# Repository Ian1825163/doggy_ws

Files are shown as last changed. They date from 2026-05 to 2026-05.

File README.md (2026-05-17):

# doggy_ws

## Overview

A 12-DOF quadruped robot project focused on kinematics, servo control, and trajectory generation.

Doggy combines a custom mechanical design, STS-series serial bus servos, inverse/forward kinematics, ROS 2 control nodes, and an Onshape-to-URDF workflow for visualization and future simulation/RL deployment.

## My role

- Designed and implemented the IK/FK pipeline
- Calibrated STS3032 servos
- Generated foot trajectories for standing, walking, and trotting tests
- Integrated control logic with the robot hardware
- Built the ROS 2 workspace for gait control, motor communication, URDF export, and deployment testing

## System architecture

- Hardware: 12-DOF quadruped frame, STS3032 serial bus servos, Teensy motor controller, Jetson Orin Nano, IMU, battery, and custom 3D/CAD components
- Software: ROS 2 Python nodes for keyboard control, gait generation, motor communication, joint-state bridging, safety gating, and RL deployment scaffolding
- Communication: Jetson publishes motor angle commands over USB serial to Teensy; Teensy sends STS bus packets to the servos; feedback bring-up is being tested through a direct STS feedback test node
- Control loop: foot trajectory generation -> IK solver -> 12 motor angle commands -> Teensy serial bridge -> STS3032 servo bus

## Demo

Add videos, GIFs, or images here:

```md
![Doggy CAD overview](docs/cad/doggy-cad-overview.png)
![Doggy front](docs/photos/doggy-front.jpg)
![Doggy side](docs/photos/doggy-side.jpg)
```

Media folders:

- CAD files and screenshots: [`docs/cad/`](docs/cad/)
- Robot photos: [`docs/photos/`](docs/photos/)

## Challenges

- Multiple IK solutions and continuity selection
- Nonlinear calf/knee linkage driven by the third motor
- STS3032 servo calibration and sign convention matching
- Real-world trajectory stability under open-loop control
- Mapping CAD/Onshape joint frames into a usable URDF

## Results

- Robot can stand with commanded servo angles
- IK validated with circular and sinusoidal foot trajectories
- Workspace and reachable foot motion were defined from the kinematic model
- Full four-leg URDF export now includes 16 DOFs, `base_link`, `imu`, and four foot frames
- ROS 2 nodes are available for gait generation, motor communication, joint-state bridging, safety gating, and STS feedback testing

## Next steps

- Open-loop walking validation on hardware
- ROS/URDF visualization and joint-state calibration
- STS3032 feedback readback through Teensy or direct servo bus adapter
- Vision / closed-loop control
- RL policy training and sim-to-real deployment

## Build

```bash
cd ~/doggy_ws
colcon build --symlink-install
source install/setup.bash
```

## Run

Scripted gait bring-up:

```bash
ros2 launch quadruped_bringup bringup.launch.py serial_port:=/dev/ttyACM0 baud_rate:=115200
```

RL deployment scaffold:

```bash
ros2 launch quadruped_bringup rl_bringup.launch.py
```

STS feedback direct-bus test:

```bash
ros2 run quadruped_control sts_feedback_test_node --ros-args \
  -p serial_port:=/dev/ttyUSB0 \
  -p baud_rate:=1000000 \
  -p servo_ids:="[1,2,3,4,5,6,7,8,9,10,11,12]"
```

## Repository layout

```text
doggy_ws/
+-- docs/
|   +-- cad/                  # CAD screenshots, Onshape notes, exported CAD files
|   +-- photos/               # Robot build photos
|   +-- rl_workflow.md        # RL deployment and bring-up notes
+-- src/
|   +-- doggy/                # Onshape-generated URDF, meshes, and config
|   +-- quadruped_bringup/    # ROS 2 launch files
|   +-- quadruped_control/    # Gait, IK, safety, feedback, and motor nodes
```

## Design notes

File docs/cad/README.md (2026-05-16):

# CAD Uploads

Put CAD-related project media here while the Doggy assembly and URDF are still being rebuilt.

Good files to keep here:

- Onshape assembly screenshots.
- Frame and mate connector screenshots.
- Exported STEP/STL snapshots that are useful for review.
- URDF tree screenshots from `check_urdf` or RViz.

Suggested names:

- `doggy-cad-overview.png`
- `doggy-urdf-frames.png`
- `doggy-assembly-notes.md`

Do not put Onshape API keys or private `.env` files in this folder.

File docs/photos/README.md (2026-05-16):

# Robot Photos

Put photos of the physical Doggy robot here.

Suggested names:

- `doggy-front.jpg`
- `doggy-side.jpg`
- `doggy-top.jpg`
- `doggy-wiring.jpg`

After uploading photos, add them to the gallery block in the root `README.md`.

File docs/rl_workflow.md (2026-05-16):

# Doggy RL Deployment Workflow

This is the working plan for moving Doggy from the current ROS 2 gait stack toward an RL policy that can be trained in simulation and deployed on the Jetson.

## Current Mechanical Check

Latest Onshape assembly checked: `doggy_ros_export`

- Estimated total mass from Onshape part mass properties: `1.348 kg`
- Mass-bearing part occurrences found: `44`
- Current local `src/doggy/robot.urdf` is the regenerated full robot export from `doggy_ros_export`.

Largest mass contributors:

| Part | Mass |
| --- | ---: |
| `teensy_battery <1>` | `0.292 kg` |
| `jetson <1>` | `0.253 kg` |
| `body upper plate v2` | `0.0898 kg` |
| `body upper plate v3` | `0.0884 kg` |
| `Feetech STS2032` motors | `0.025 kg` each |
| `foot` | `0.020 kg` each |

Current URDF status:

- `onshape-to-robot doggy` finds all four legs and 16 DOFs.
- `check_urdf src/doggy/robot.urdf` succeeds.
- Root link is `body`.
- Frames exported as links: `base_link`, `imu`, `RL_foot`, `RR_foot`, `FR_foot`, `FL_foot`.
- URDF total inertial mass: `1.348077 kg`.

Regenerate and validate after CAD changes:

```bash
cd ~/doggy_ws/src
onshape-to-robot doggy
cd ~/doggy_ws
check_urdf src/doggy/robot.urdf
```

## Runtime Architecture

Keep motor commands and visualization state separate:

```text
gait_generator_node
  publishes /joint_angles directly in scripted gait mode

policy_node
  publishes /joint_angles_unsafe in RL mode

safety_node
  clamps /joint_angles_unsafe into /joint_angles

motor_control_node
  subscribes /joint_angles
  sends 12 real motor angles to Teensy

joint_state_bridge_node
  subscribes /joint_angles
  computes passive knee angles from nonlinear linkage FK
  publishes /joint_states

robot_state_publisher
  subscribes /joint_states
  publishes TF from the URDF
```

The URDF should include both motor joints and passive knee joints, but the nonlinear relation should not be encoded as a URDF mimic or gear relation.

Use this mapping for the current command order:

```text
/joint_angles:
  LB1 LB2 LB3 | RB1 RB2 RB3 | RF1 RF2 RF3 | LF1 LF2 LF3

Leg names:
  LB -> RL
  RB -> RR
  RF -> FR
  LF -> FL
```

For each leg:

```text
hip_roll  = motor 1
hip_pitch = motor 2
motor3    = real third motor angle
knee      = nonlinear_linkage_fk(motor3)
```

## ROS Nodes

1. `joint_state_bridge_node` implemented in `quadruped_control`

   Inputs:

   - `/joint_angles` as `std_msgs/Float32MultiArray`

   Outputs:

   - `/joint_states` as `sensor_msgs/JointState`

   Responsibilities:

   - Convert degrees to radians.
   - Rename command array indices into URDF joint names.
   - Compute `*_knee` from `*_motor3` using the MATLAB/Python linkage FK.
   - Apply per-leg sign and zero offsets.

   Run:

   ```bash
   ros2 run quadruped_control joint_state_bridge_node
   ```

2. `policy_node` implemented as a deployment scaffold

   Inputs:

   - `/gait_cmd`

   Outputs:

   - `/joint_angles_unsafe`

   Responsibilities:

   - Keep a stable ROS interface for the future trained policy.
   - Publish a safe stand pose while no inference backend is wired.
   - Later: load the trained policy and output 12 motor target angles.

   Run:

   ```bash
   ros2 run quadruped_control policy_node
   ```

3. `safety_node` implemented in `quadruped_control`

   Responsibilities:

   - Gate `/joint_angles_unsafe` into `/joint_angles`.
   - Clamp joint angle commands.
   - Command timeout handling.
   - Publish stand pose on timeout or disabled state.
   - Later: add IMU tilt/fall checks and motor feedback checks.

   Run:

   ```bash
   ros2 run quadruped_control safety_node
   ```

Launch options:

```bash
# Existing scripted gait path, now also publishing /joint_states
ros2 launch quadruped_bringup bringup.launch.py

# RL deployment path:
# policy_node -> safety_node -> /joint_angles -> motor_control_node
ros2 launch quadruped_bringup rl_bringup.launch.py
```

## Calibration Before RL

Finish these before trusting sim-to-real:

1. Motor zero offsets for all 12 actuators.
2. Motor sign convention for all four legs.
3. Passive knee sign and offset:

   ```text
   urdf_knee = sign * linkage_theta4(motor3) + offset
   ```

4. IMU frame orientation against `base_link`.
5. Foot frames at the foot-tip sphere centers.
6. Joint limits checked against physical hard stops.
7. Standing pose verified in RViz and on hardware.

## Training Plan

Preferred setup:

- Train on a desktop/cloud machine with GPU.
- Deploy only the exported policy on Jetson Orin Nano.
- Keep Jetson runtime simple: ROS 2 node, inference, safety clamps, serial motor bridge.

Simulation choices:

- Isaac Lab if GPU training and terrain/domain randomization matter most.
- MuJoCo if fast iteration and easier model debugging matter most.

Policy interface:

- Observation:
  - base orientation and angular velocity
  - commanded velocity
  - 12 motor positions
  - 12 motor velocities when available
  - previous action
  - optional gait phase
  - optional foot contact states
- Action:
  - 12 target motor angles, or 12 residual offsets around a nominal gait
- Control rate:
  - start with `50 Hz`, matching the current gait generator

Rewards:

- velocity tracking
- upright body orientation
- target body height
- low energy / smooth action
- foot clearance during swing
- low foot slip during stance
- joint limit avoidance
- fall penalty

Domain randomization:

- total mass around `1.348 kg`
- per-link mass and COM offsets
- motor strength
- joint damping/friction
- ground friction
- IMU noise and bias
- command latency
- battery/Jetson payload variation

## Deployment Stages

1. URDF validation

   - Fix `frame_base_link`.
   - Export full URDF.
   - Check root link is body/base.
   - Confirm all foot frames and IMU frame appear.
   - Confirm mass and inertials are reasonable.

2. Visualization bridge

   - Add `joint_state_bridge_node`.
   - Publish `/joint_states` from existing `/joint_angles`.
   - Confirm RViz motion matches the physical leg direction.

3. Hardware baseline

   - Stand pose only.
   - Slow scripted leg sweep.
   - Low-speed gait with rosbag recording.
   - Check communication drop rate.

4. Simulation baseline

   - Import URDF/MJCF/USD.
   - Reproduce standing pose.
   - Reproduce current scripted gait.
   - Validate foot locations and joint signs.

5. RL training

   - Start with stand/balance.
   - Add commanded forward velocity.
   - Add yaw command.
   - Add terrain and pushes only after flat ground works.

6. Sim-to-real rollout

   - Policy disabled by default.
   - E-stop active.
   - Test on stand or suspended robot first.
   - Touchdown test at low action scale.
   - Increase action scale and command speed gradually.

## Bag Topics

Record these for debugging:

```bash
ros2 bag record \
  /joint_angles \
  /joint_states \
  /imu \
  /gait_cmd \
  /comm_stats \
  /teensy_ack \
  /teensy_hb
```

Add later when available:

- `/cmd_vel`
- `/motor_feedback`
- `/foot_contacts`
- `/policy_debug`

## STS3032 Feedback Bring-Up

Current `src/teensy_motor.ino` writes STS sync-write packets on `Serial4`, but
it does not yet forward USB packets to the STS bus or send motor feedback back
to Jetson. To test feedback now, connect Jetson to the STS bus through a direct
USB servo adapter, or add a Teensy bridge/readback firmware path first.

Direct bus feedback test:

```bash
ros2 run quadruped_control sts_feedback_test_node --ros-args \
  -p serial_port:=/dev/ttyUSB0 \
  -p baud_rate:=1000000 \
  -p servo_ids:="[1,2,3,4,5,6,7,8,9,10,11,12]"
```

Watch the raw JSON:

```bash
ros2 topic echo /sts_feedback_raw
```

The test node reads from register `56` with length `8`, which covers present
position plus the adjacent raw status bytes used for early bring-up.

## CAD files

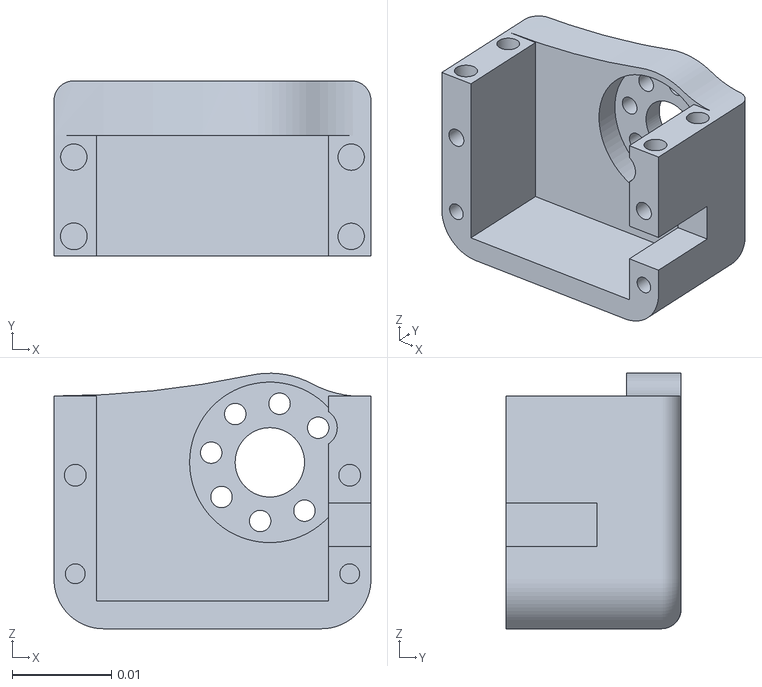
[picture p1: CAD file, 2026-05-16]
src/doggy/assets/hipjoint_v4__2.stl
0.032 x 0.0177 x 0.0258

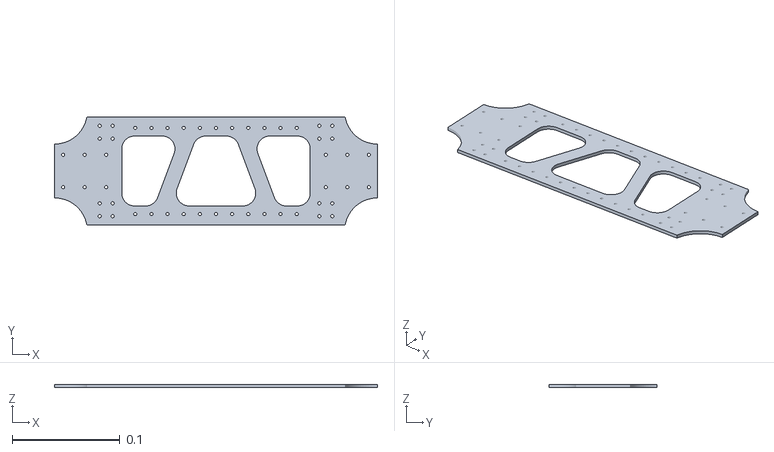
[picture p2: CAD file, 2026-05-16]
src/doggy/assets/身體上板_v3.stl
0.3 x 0.1 x 0.003

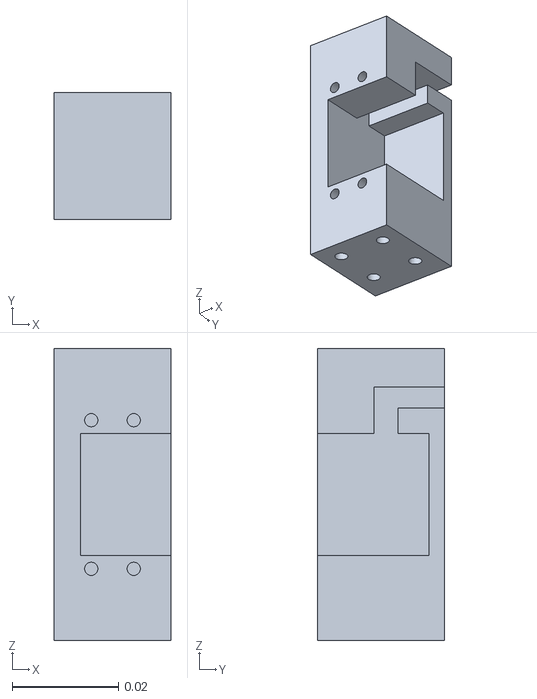
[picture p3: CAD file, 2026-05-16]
src/doggy/assets/motor_holder_for_onshape_mir.stl
0.022 x 0.024 x 0.055

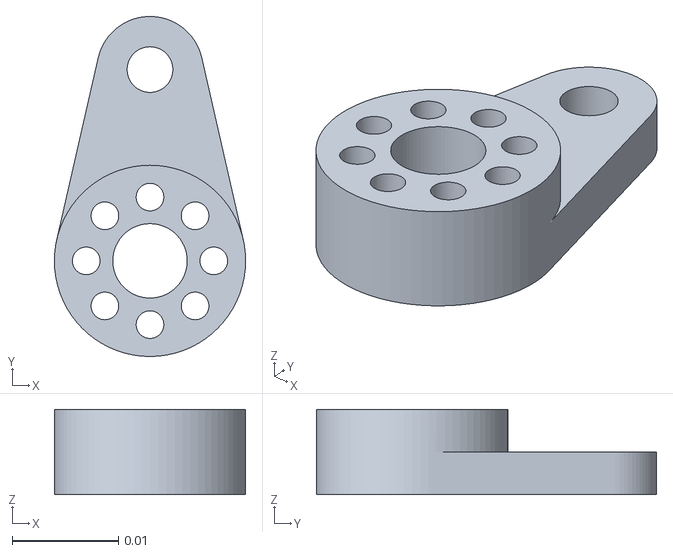
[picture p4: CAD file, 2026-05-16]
src/doggy/assets/linkage_a_v2_0713_mir.stl
0.018 x 0.032 x 0.008

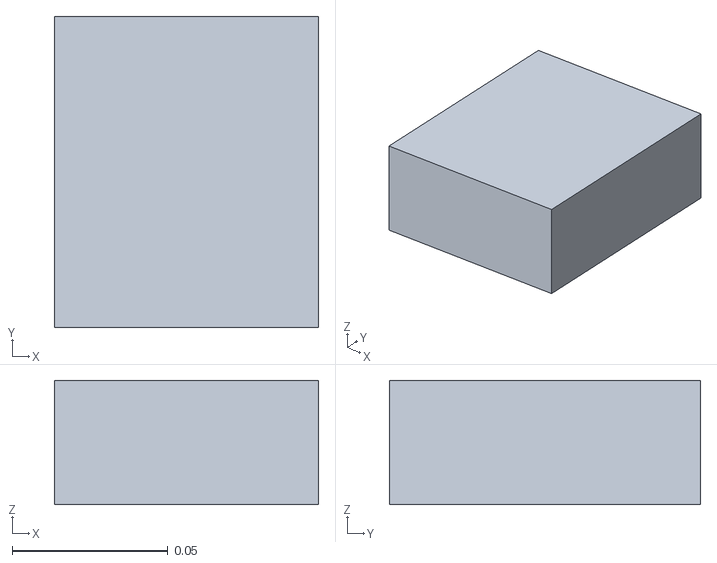
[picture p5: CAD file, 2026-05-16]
src/doggy/assets/part_1__2.stl
0.085 x 0.1 x 0.04

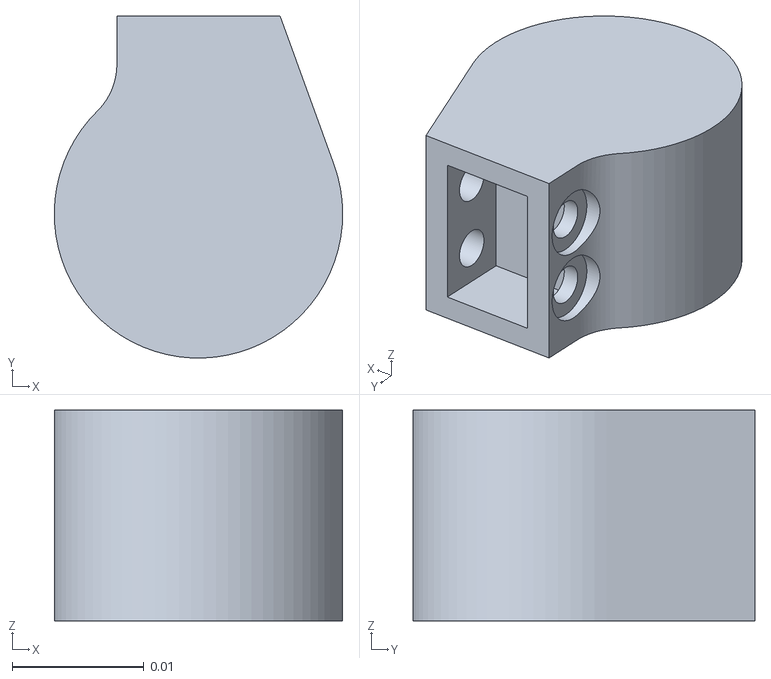
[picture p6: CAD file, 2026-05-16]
src/doggy/assets/角頭v2.stl
0.0219 x 0.026 x 0.016

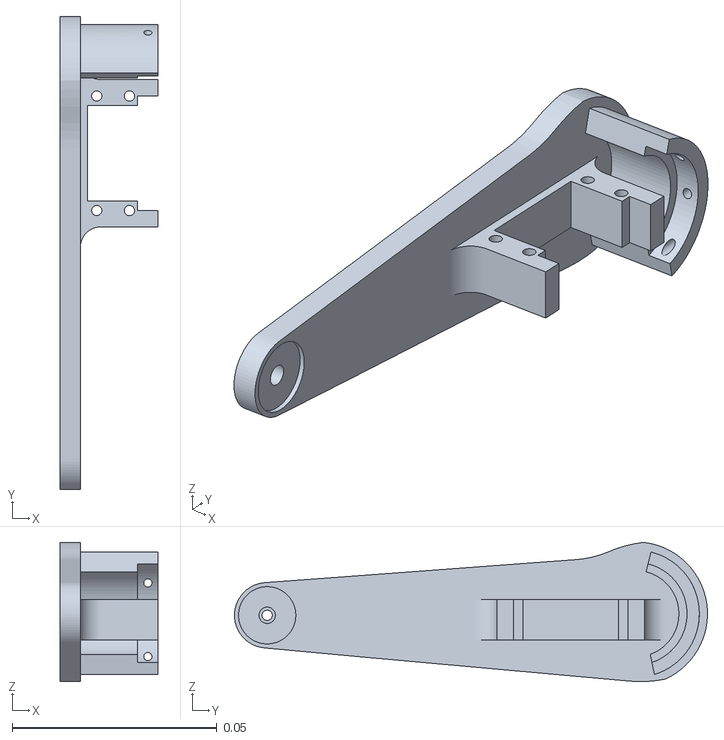
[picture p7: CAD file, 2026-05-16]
src/doggy/assets/out_leg_v4_mirrored.stl
0.024 x 0.116 x 0.034

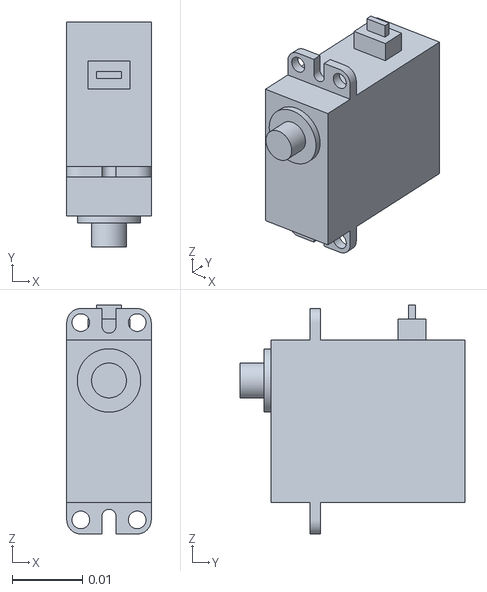
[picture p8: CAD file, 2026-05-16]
src/doggy/assets/feetech_sts2032_20g.stl
0.012 x 0.0319 x 0.0325

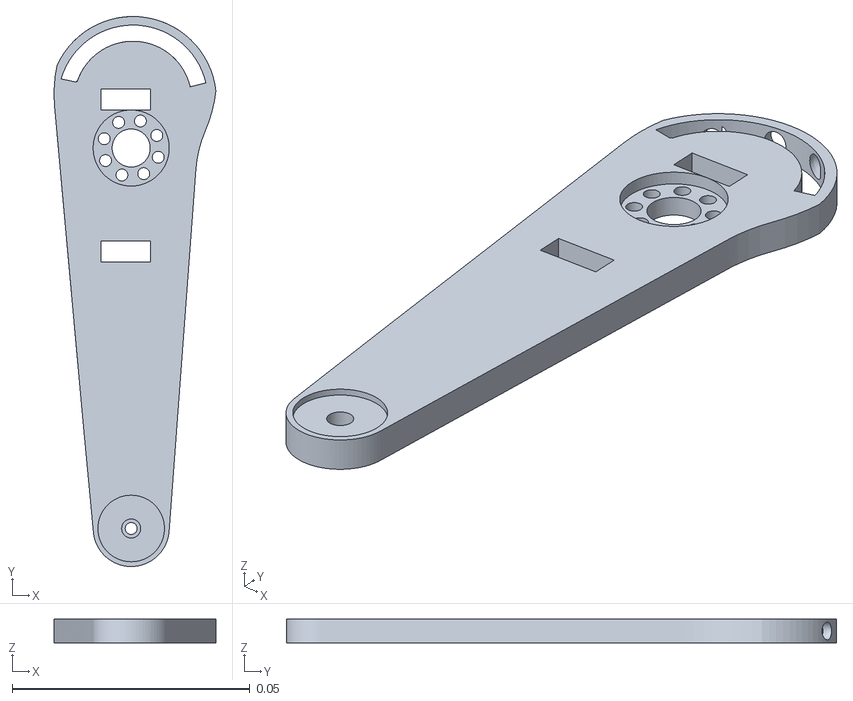
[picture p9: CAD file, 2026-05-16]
src/doggy/assets/inner_leg_v4__2.stl
0.034 x 0.116 x 0.005

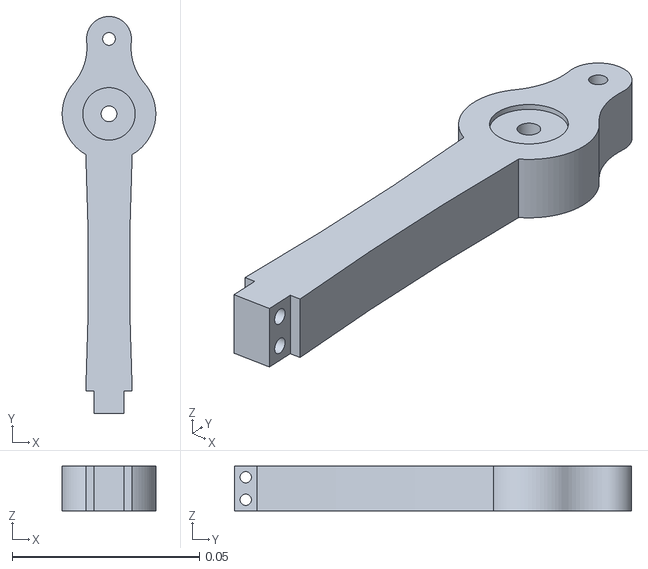
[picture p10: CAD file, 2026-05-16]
src/doggy/assets/foot_v4.stl
0.025 x 0.106 x 0.012

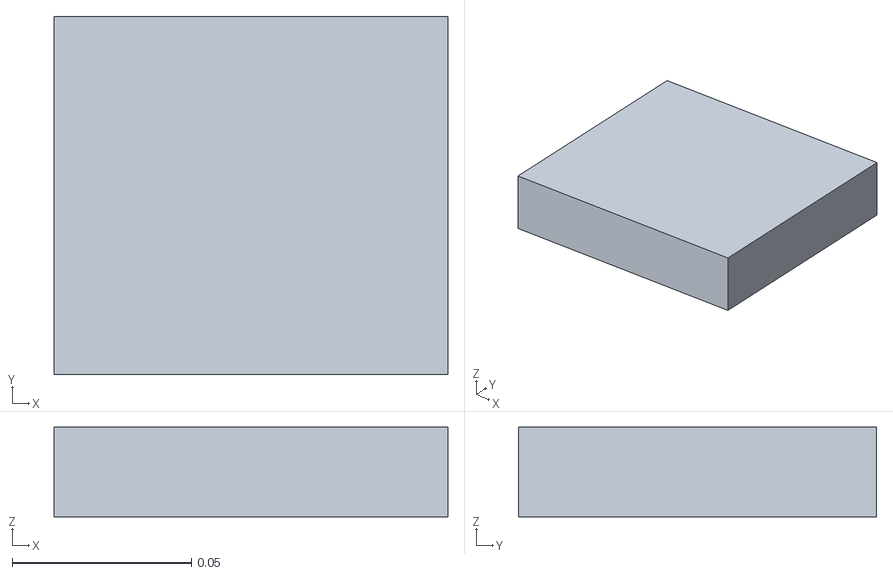
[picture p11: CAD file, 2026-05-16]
src/doggy/assets/part_1.stl
0.11 x 0.1 x 0.025

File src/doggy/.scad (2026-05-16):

% scale(1000) import(".");

// Append pure shapes (cube, cylinder and sphere), e.g:
// cube([10, 10, 10], center=true);
// cylinder(r=10, h=10, center=true);
// sphere(10);

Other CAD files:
src/doggy/assets/motor_holder_for_onshape.stl
src/doggy/assets/out_leg_v4__2.stl
src/doggy/assets/out_leg_v4.stl
src/doggy/assets/inner_leg_v4_mirrored.stl
src/doggy/foot_tip.scad
src/doggy/assets/calf.scad
src/doggy/assets/foot.scad
src/doggy/assets/foot_tip.scad
src/doggy/assets/hipjoint_v4.stl
src/doggy/assets/inner_leg_v4.stl
src/doggy/assets/身體上板_v2.stl

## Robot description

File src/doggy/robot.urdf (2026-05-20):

<?xml version="1.0" ?>
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
<robot name="doggy">
  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
  <link name="body">
    <inertial>
      <origin xyz="7.47198e-16 -5.12135e-17 0.0124695" rpy="0 0 0"/>
      <mass value="0.918789"/>
      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
    </inertial>
    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
  </link>
  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
  <link name="imu">
    <origin xyz="0 0 0" rpy="0 -0 0"/>
    <inertial>
      <origin xyz="0 0 0" rpy="0 0 0"/>
      <mass value="1e-9"/>
      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
    </inertial>
  </link>
  <joint name="imu_frame" type="fixed">
    <origin xyz="-2.89644e-18 -2.1684e-18 -0.0145" rpy="0 -0 3.14159"/>
    <parent link="body"/>
    <child link="imu"/>
    <axis xyz="0 0 0"/>
  </joint>
  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
  <link name="base_link">
    <origin xyz="0 0 0" rpy="0 -0 0"/>
    <inertial>
      <origin xyz="0 0 0" rpy="0 0 0"/>
      <mass value="1e-9"/>
      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
    </inertial>
  </link>
  <joint name="base_link_frame" type="fixed">
    <origin xyz="-2.89644e-18 -2.35336e-18 0.003" rpy="-3.24138e-43 -8.96831e-44 -3.14159"/>
    <parent link="body"/>
    <child link="base_link"/>
    <axis xyz="0 0 0"/>
  </joint>
  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
  <link name="hipjoint">
    <inertial>
      <origin xyz="-0.00584991 -0.00133744 -0.0104817" rpy="0 0 0"/>
      <mass value="0.0326833"/>
      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
    </inertial>
    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
  </link>
  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
  <link name="thigh_mir">
    <inertial>
      <origin xyz="0.000153018 -0.019063 -0.0124043" rpy="0 0 0"/>
      <mass value="0.0369251"/>
      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
    </inertial>
    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
  </link>
  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
  <link name="calf">
    <inertial>
      <origin xyz="3.21658e-05 0.0313528 -0.0050139" rpy="0 0 0"/>
      <mass value="0.023"/>
      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
    </inertial>
    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
  </link>
  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
  <link name="RL_foot">
    <origin xyz="0 0 0" rpy="0 -0 0"/>
    <inertial>
      <origin xyz="0 0 0" rpy="0 0 0"/>
      <mass value="1e-9"/>
      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
    </inertial>
  </link>
  <joint name="RL_foot_frame" type="fixed">
    <origin xyz="-3e-06 0.0919 -0.005" rpy="-1.5708 1.27732e-31 3.14159"/>
    <parent link="calf"/>
    <child link="RL_foot"/>
    <axis xyz="0 0 0"/>
  </joint>
  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
  <joint name="RL_knee" type="revolute">
    <origin xyz="2.30043e-13 -0.08 -0.007" rpy="6.12323e-17 -6.30424e-31 1.5708"/>
    <parent link="thigh_mir"/>
    <child link="calf"/>
    <axis xyz="0 0 1"/>
    <limit effort="10" velocity="10" lower="-1.309" upper="1.5708"/>
  </joint>
  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
  <joint name="RL_hip_pitch" type="revolute">
    <origin xyz="-1.11022e-16 0.0187 -0.0117" rpy="-1.5708 -3.06162e-16 -3.14159"/>
    <parent link="hipjoint"/>
    <child link="thigh_mir"/>
    <axis xyz="0 0 1"/>
    <limit effort="10" velocity="10" lower="-1.5708" upper="0.174533"/>
  </joint>
  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
  <joint name="RL_hip_roll" type="revolute">
    <origin xyz="0.125 -0.036 -0.00279" rpy="-3.14159 1.5708 0"/>
    <parent link="body"/>
    <child link="hipjoint"/>
    <axis xyz="0 0 1"/>
    <limit effort="10" velocity="10" lower="-0.349066" upper="0.174533"/>
  </joint>
  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
  <link name="hipjoint_mir">
    <inertial>
      <origin xyz="-0.00584991 0.00133744 -0.0104817" rpy="0 0 0"/>
      <mass value="0.0326833"/>
      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
    </inertial>
    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
  </link>
  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
  <link name="thigh_mir_2">
    <inertial>
      <origin xyz="0.000153018 -0.019063 -0.0124043" rpy="0 0 0"/>
      <mass value="0.0369251"/>
      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
    </inertial>
    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
  </link>
  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
  <link name="calf_2">
    <inertial>
      <origin xyz="3.21658e-05 0.0313528 -0.0060139" rpy="0 0 0"/>
      <mass value="0.023"/>
      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
    </inertial>
    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
  </link>
  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
  <link name="FL_foot">
    <origin xyz="0 0 0" rpy="0 -0 0"/>
    <inertial>
      <origin xyz="0 0 0" rpy="0 0 0"/>
      <mass value="1e-9"/>
      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
    </inertial>
  </link>
  <joint name="FL_foot_frame" type="fixed">
    <origin xyz="-3e-06 0.0919 -0.006" rpy="-1.5708 -5.14606e-32 3.14159"/>
    <parent link="calf_2"/>
    <child link="FL_foot"/>
    <axis xyz="0 0 0"/>
  </joint>
  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
  <joint name="FL_knee" type="revolute">
    <origin xyz="2.30081e-13 -0.08 -0.006" rpy="-6.70532e-30 -7.2455e-30 1.5708"/>
    <parent link="thigh_mir_2"/>
    <child link="calf_2"/>
    <axis xyz="0 0 1"/>
    <limit effort="10" velocity="10" lower="-1.309" upper="1.5708"/>
  </joint>
  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
  <joint name="FL_hip_pitch" type="revolute">
    <origin xyz="1.25767e-17 -0.0187 -0.0117" rpy="1.5708 -9.36772e-31 -3.14159"/>
    <parent link="hipjoint_mir"/>
    <child link="thigh_mir_2"/>
    <axis xyz="0 0 1"/>
    <limit effort="10" velocity="10" lower="-1.5708" upper="0.174533"/>
  </joint>
  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
  <joint name="FL_hip_roll" type="revolute">
    <origin xyz="-0.125 -0.036 -0.00279" rpy="-1.51223e-15 1.5708 0"/>
    <parent link="body"/>
    <child link="hipjoint_mir"/>
    <axis xyz="0 0 1"/>
    <limit effort="10" velocity="10" lower="-0.174533" upper="0.349066"/>
  </joint>
  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
  <link name="hipjoint_2">
    <inertial>
      <origin xyz="-0.00584991 -0.00133744 -0.0104817" rpy="0 0 0"/>
      <mass value="0.0326833"/>
      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
    </inertial>
    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
  </link>
  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
  <link name="thigh">
    <inertial>
      <origin xyz="-5.38791e-05 0.013613 -0.0118373" rpy="0 0 0"/>
      <mass value="0.0619252"/>
      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
    </inertial>
    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
  </link>
  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
  <link name="calf_3">
    <inertial>
      <origin xyz="3.21658e-05 -0.0313528 -0.0059861" rpy="0 0 0"/>
      <mass value="0.023"/>
      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
    </inertial>
    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
  </link>
  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
  <link name="FR_foot">
    <origin xyz="0 0 0" rpy="0 -0 0"/>
    <inertial>
      <origin xyz="0 0 0" rpy="0 0 0"/>
      <mass value="1e-9"/>
      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
    </inertial>
  </link>
  <joint name="FR_foot_frame" type="fixed">
    <origin xyz="-3e-06 -0.0919 -0.006" rpy="1.5708 5.52464e-33 3.14159"/>
    <parent link="calf_3"/>
    <child link="FR_foot"/>
    <axis xyz="0 0 0"/>
  </joint>
  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
  <joint name="FR_knee" type="revolute">
    <origin xyz="2.29983e-13 0.08 -0.006" rpy="3.36134e-27 -4.48177e-28 -1.5708"/>
    <parent link="thigh"/>
    <child link="calf_3"/>
    <axis xyz="0 0 1"/>
    <limit effort="10" velocity="10" lower="-1.309" upper="1.5708"/>
  </joint>
  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
  <joint name="FR_hip_pitch" type="revolute">
    <origin xyz="-1.01048e-16 0.0187 -0.0117" rpy="-1.5708 8.48025e-30 -3.14159"/>
    <parent link="hipjoint_2"/>
    <child link="thigh"/>
    <axis xyz="0 0 1"/>
    <limit effort="10" velocity="10" lower="-0.174533" upper="1.5708"/>
  </joint>
  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
  <joint name="FR_hip_roll" type="revolute">
    <origin xyz="-0.125 0.036 -0.00279" rpy="-6.89354e-17 1.5708 0"/>
    <parent link="body"/>
    <child link="hipjoint_2"/>
    <axis xyz="0 0 1"/>
    <limit effort="10" velocity="10" lower="-0.349066" upper="0.174533"/>
  </joint>
  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
  <link name="hipjoint_mir_2">
    <inertial>
      <origin xyz="-0.00584991 0.00133744 -0.0104817" rpy="0 0 0"/>
      <mass value="0.0326833"/>
      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
    </inertial>
    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
  </link>
  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
  <link name="thigh_2">
    <inertial>
      <origin xyz="-5.38791e-05 0.013613 -0.0118373" rpy="0 0 0"/>
      <mass value="0.0619252"/>
      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
    </inertial>
    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
  </link>
  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
  <link name="calf_4">
    <inertial>
      <origin xyz="3.21658e-05 -0.0313528 -0.0059861" rpy="0 0 0"/>
      <mass value="0.023"/>
      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
    </inertial>
    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
  </link>
  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
  <link name="RR_foot">
    <origin xyz="0 0 0" rpy="0 -0 0"/>
    <inertial>
      <origin xyz="0 0 0" rpy="0 0 0"/>
      <mass value="1e-9"/>
      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
    </inertial>
  </link>
  <joint name="RR_foot_frame" type="fixed">
    <origin xyz="-3e-06 -0.0919 -0.006" rpy="1.5708 -1.39172e-31 3.14159"/>
    <parent link="calf_4"/>
    <child link="RR_foot"/>
    <axis xyz="0 0 0"/>
  </joint>
  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
  <joint name="RR_knee" type="revolute">
    <origin xyz="2.30041e-13 0.08 -0.006" rpy="-1.49884e-29 4.87234e-30 -1.5708"/>
    <parent link="thigh_2"/>
    <child link="calf_4"/>
    <axis xyz="0 0 1"/>
    <limit effort="10" velocity="10" lower="-1.5708" upper="1.309"/>
  </joint>
  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
  <joint name="RR_hip_pitch" type="revolute">
    <origin xyz="1.25767e-17 -0.0187 -0.0117" rpy="1.5708 -3.24173e-30 3.14159"/>
    <parent link="hipjoint_mir_2"/>
    <child link="thigh_2"/>
    <axis xyz="0 0 1"/>
    <limit effort="10" velocity="10" lower="-0.174533" upper="1.5708"/>
  </joint>
  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

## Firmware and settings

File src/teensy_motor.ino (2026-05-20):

#include <Arduino.h>
#include <math.h>
#include <IntervalTimer.h>
#include <stdlib.h>
#include <string.h>


struct Vec3 {
  double x, y, z;
};
class Leg;  


// -----------------------------
//  Config
// -----------------------------
static constexpr uint32_t BAUD_SERVO = 1000000;
static constexpr uint32_t BAUD_USB   = 115200;

// ROS bridge mode:
//   Jetson -> Teensy: $ANGLES,<seq>,d1,d2,...,d12\n
//   Teensy -> Jetson: $ACK,<seq>,1\n and $HB,<seq>\n
static constexpr bool ENABLE_ROS_BRIDGE = true;
static constexpr uint32_t HEARTBEAT_MS = 100;          // 10 Hz
static constexpr uint32_t COMMAND_TIMEOUT_MS = 500;    // fall back to stand
static constexpr uint32_t FAILSAFE_STAND_MS = 100;     // resend stand at 10 Hz


static constexpr uint16_t CENTER_TICK = 2048;   // STS 12-bit center
static constexpr uint16_t GOAL_SPEED  = 1000;   // 0x03E8
static constexpr uint16_t GOAL_TIME   = 200;    // don't use 0 at first (gentler)


static constexpr bool ENABLE_TIMER = true;     // false: test stable position; true for real time control
static constexpr bool ENABLE_TRAJ  = true;    
static constexpr uint32_t CTRL_US  = 20000;     // 20ms => 50Hz


// Angle safety clamp (deg)
static constexpr double LIMIT_DEG = 70.0;


const double T = 2.0;
const double omega = 2.0 * M_PI / T;
const double lift = 10.0;
const double disp = 30.0;


//gait control parameter
static double phase = 0.0;
const double phaseRate = 1.0 / T;   // 1/T cycle per second




// -----------------------------
//  Utils
// -----------------------------
inline double clampd(double v, double lo, double hi){
  return (v < lo) ? lo : (v > hi) ? hi : v;
}
inline double deg2rad(double d){ return d * M_PI / 180.0; }
inline double rad2deg(double r){ return r * 180.0 / M_PI; }


inline int16_t wrap4096(int32_t v){
  v %= 4096;
  if(v < 0) v += 4096;
  return (int16_t)v;
}


// rad -> tick offset (can be negative)
inline int32_t rad2tick_offset(double rad){
  return (int32_t)lround(rad * (4096.0 / (2.0*M_PI)));
}


// center + rad (safe wrap 0..4095)
inline uint16_t centerPlusRad(double rad){
  int32_t goal = (int32_t)CENTER_TICK + rad2tick_offset(rad);
  return (uint16_t)wrap4096(goal);
}


inline double wrapPi(double a){
  while(a <= -M_PI) a += 2.0*M_PI;
  while(a >   M_PI) a -= 2.0*M_PI;
  return a;
}
inline double wrap01(double p){
  p = fmod(p, 1.0);
  if(p < 0) p+=1;
  return p;
}
inline double angDiff(double a, double b){
  return wrapPi(a - b);
}




// -----------------------------
//  Debug shared (main loop prints)
// -----------------------------
volatile double debug_x = 0, debug_y = 0, debug_z = 0;
volatile double debug_a1 = 0, debug_a2 = 0, debug_a3 = 0;


unsigned long lastPrintTime = 0;


// -----------------------------
//  Leg class (你的 IK 保留，微調安全)
// -----------------------------
class Leg {
public:
  bool inited_c;
  double last_c_local;


    // --- NEW: FK 4-bar state (theta4 root memory) ---
  bool inited_theta4;
  int  last_theta4_choice;   // 1 or 2


  // --- NEW: IK branch selection state (c1/c2 hysteresis) ---
  bool inited_pick;
  int  last_pick;            // 1=c1, 2=c2




  const double L1;
  const int L2;
  const int L3;
  const int L4;
  const double h;
  const int r;


  // NEW: FK params
  const int R3;
  const int R4;


  double angle1;
  double angle2;
  double angle3;
  double pos[3];


  double z_on;
  double z_off;


  bool use_c2;


  Leg();
  void setTargetPosition(double x, double y, double z);
  void setTargetAngle(double a1, double a2, double a3);
  void computeIK();
    // --- NEW: FK + selection ---
  Vec3 fkEndEffector(double alp, double bet, double gamm, bool do_update);
  void computeIK_FKSelect();      


};


void lift_trajectory(Leg& leg, double t);
void sinusoidal_trajectory(Leg& leg, double p, double duty);
void standing_pose(Leg& leg);
void squat_pose(Leg& leg);


void trot(Leg& RB, Leg& RF, Leg& LB, Leg& LF, double phase);
void walk(Leg& RB, Leg& RF, Leg& LB, Leg& LF, double phase);
void lean(Leg& RB, Leg& RF, Leg& LB, Leg& LF);


void sendMotorPacketDeg(double d1, double d2, double d3,
                        double d4, double d5, double d6,
                        double d7, double d8, double d9,
                        double d10,double d11,double d12);
void sendMotorPacketDegArray(const double deg[12]);
void sendStandPose();
void handleUsbSerial();
void handleCommandLine(const char* line);
bool parseAnglesLine(const char* line, uint32_t& seq, double deg[12]);
uint32_t parseSeqBestEffort(const char* line);
void sendAck(uint32_t seq, bool ok);
void sendHeartbeat();




Leg::Leg()
  : inited_c(false),
    last_c_local(0.0),    
    inited_theta4(false),
    last_theta4_choice(1),
    inited_pick(false),
    last_pick(1),
    L1(26.086),
    L2(80),
    L3(80),
    L4(20),
    h(28.5),
    r(22),
    R3(20),
    R4(80),


    angle1(M_PI/2),
    angle2(M_PI/2),
    angle3(M_PI/2),
    z_on(-123.0),
    z_off(-123.0),
    use_c2(false)
   
{
  pos[0] = 26.086;
  pos[1] = 0.0;
  pos[2] = -155.0;
}


void Leg::setTargetPosition(double x, double y, double z){
  pos[0] = x;
  pos[1] = y;
  pos[2] = z;
}


void Leg::computeIK(){
  double x = pos[0], y = pos[1], z = pos[2];


  double l2 = x*x + y*y + z*z;
  double l  = sqrt(l2);
  if(l < 1e-6) l = 1e-6;


  double d2 = l2 - L1*L1;
  if(d2 < 0) d2 = 0;
  double d  = sqrt(d2);
  if(d < 1e-6) d = 1e-6;


  // knee geometry
  double cosK = (L1*L1 + (double)L2*L2 + (double)L3*L3 - l2) / (2.0*L2*L3);
  cosK = clampd(cosK, -1.0, 1.0);
  double theta_k = acos(cosK);


  // theta_b
  double s1 = clampd(y/d, -1.0, 1.0);
  double cos2 = ((double)L2*L2 + d*d - (double)L3*L3) / (2.0*L2*d);
  cos2 = clampd(cos2, -1.0, 1.0);
  double theta_b = M_PI/2.0 - (asin(s1) + acos(cos2));


  // theta_a
  double ca = clampd(L1 / l, -1.0, 1.0);
  double theta_a = atan2(x, fabs(z)) + acos(ca) - M_PI/2.0;


  // theta_c (your linkage)
  double A = 2.0*r*(L4*cos(theta_k) + L2);
  double B = 6.0*r;
  double C = (double)r*r + pow((double)L2 + L4*cos(theta_k), 2)
           + 9.0 + pow(L4*sin(theta_k) - h, 2) - (double)L3*L3;


  double disc = (A*B)*(A*B) - (A*A - C*C)*(B*B - C*C);
  double sq = sqrt(fmax(disc, 0.0));


  double Y1 = -A*B + sq;
  double Y2 = -A*B - sq;
  double X  = A*A - C*C;
  double c1 = wrapPi(atan2(Y1, X));
  double c2 = wrapPi(atan2(Y2, X));


  // adjust the new anhle value to be neraest to ref (+-2pi）, avoid jumping sol
  auto unwrapToNear = [&](double a, double ref){
      return ref + angDiff(a, ref);   // angDiff : (-pi,pi]
  };
  double z_now = z; //get z value


  if(!this->inited_c){
      // determine first theta_c
      if(z_now >= this->z_on) this->last_c_local = c1;
      else {
        this->use_c2 = true;
        this->last_c_local = c2;
      }
      this->inited_c = true;
  }
  else {
      double c1u = unwrapToNear(c1, this->last_c_local);
      double c2u = unwrapToNear(c2, this->last_c_local);


      if(this->use_c2){
          if(z_now >= this->z_off) {
            this->use_c2 = false;
            this->last_c_local = c1u;
          }
          else this->last_c_local = c2u;
          }
      else {
        if(z_now >= this->z_on){
          double err1 = fabs(c1u - this->last_c_local);
          double err2 = fabs(c2u - this->last_c_local);
          err1 = min(err1, 2*M_PI - err1);
          err2 = min(err2, 2*M_PI - err2);
          if (err1 <= err2)
              this->last_c_local = c1u;
          else
              this->last_c_local = c2u;


        }
        else {
          this->last_c_local = c2u;
          this->use_c2 = true;


        }
      }
  }


  double chosen = this->last_c_local;


  // --- 5. Store Final Angles ---
  this->angle1 = wrapPi(theta_a);
  this->angle2 = wrapPi(theta_b);
  this->angle3 = chosen;   // wrap to (-pi,pi)


}
// apply R = Ry(alp) * Rx(bet)
static inline Vec3 R_apply(double alp, double bet, const Vec3& v){
  double cb = cos(bet), sb = sin(bet);
  // Rx(bet)
  Vec3 v1 { v.x, cb*v.y + sb*v.z, -sb*v.y + cb*v.z };


  double ca = cos(alp), sa = sin(alp);
  // Ry(alp)
  Vec3 v2 { ca*v1.x - sa*v1.z, v1.y, sa*v1.x + ca*v1.z };
  return v2;
}


Vec3 Leg::fkEndEffector(double alp, double bet, double gamm, bool do_update){
  // --- theta4 candidates (same as MATLAB) ---
  double a_ = r * sin(gamm);
  double R1_ = sqrt(a_*a_ + h*h);
  double R2_ = sqrt((double)R4*R4 - pow(r*cos(gamm) - 3.0, 2)); // R2 = sqrt(R4^2-(r*cos(g)-3)^2)
  double theta1 = atan2(h, a_);


  double A = 2.0*R1_*R3*sin(theta1);
  double B = 2.0*R1_*R3*cos(theta1) - 2.0*R3*R4;
  double C = R1_*R1_ - R2_*R2_ + (double)R3*R3 + (double)R4*R4 - 2.0*R1_*R4*cos(theta1);


  double disc = C*C * (A*A + B*B - C*C);
  disc = fmax(disc, 0.0);
  double sq = sqrt(disc);


  double th4_1 = atan2(-A*B + sq, A*A - C*C);
  double th4_2 = atan2(-A*B - sq, A*A - C*C);


  // --- error metric (distance should be L3=80) ---
  // B_local_check = [r*cos(g); r*sin(g); h]
  double Bx = r*cos(gamm);
  double By = r*sin(gamm);
  double Bz = h;


  // C1_local = [3; R4 + R3*cos(th4); R3*sin(th4)]
  auto distErr = [&](double th4){
    double C1x = 3.0;
    double C1y = (double)R4 + (double)R3 * cos(th4);
    double C1z = (double)R3 * sin(th4);
    double dx = Bx - C1x, dy = By - C1y, dz = Bz - C1z;
    double d = sqrt(dx*dx + dy*dy + dz*dz);
    return fabs(d - (double)L3);
  };


  double e1 = distErr(th4_1);
  double e2 = distErr(th4_2);


  // --- hysteresis keep continuity (same spirit as MATLAB) ---
  if(!inited_theta4){
    last_theta4_choice = (e1 <= e2) ? 1 : 2;
    inited_theta4 = true;
  }else{
    const double threshold = 0.4;
    if(last_theta4_choice == 1){
      if(e2 < e1 - threshold) last_theta4_choice = 2;
    }else{
      if(e1 < e2 - threshold) last_theta4_choice = 1;
    }
  }


  // if evaluating only, DO NOT update memory
  int choice = last_theta4_choice;
  if(!do_update){
    // compute what choice would be, without changing stored
    choice = (e1 <= e2) ? 1 : 2;
    const double threshold = 0.4;
    if(last_theta4_choice == 1){
      if(e2 < e1 - threshold) choice = 2;
      else choice = 1;
    }else{
      if(e1 < e2 - threshold) choice = 1;
      else choice = 2;
    }
  }


  double th4 = (choice == 1) ? th4_1 : th4_2;


  // if do_update=true, commit
  if(do_update){
    last_theta4_choice = choice;
  }


  // --- compute E_local and transform to global ---
  // D_local = [0; R4; 0]
  // E_local = D_local - [0; R4*cos(th4); R4*sin(th4)] = [0; R4*(1-cos); -R4*sin]
  Vec3 E_local { 0.0, (double)R4 * (1.0 - cos(th4)), -(double)R4 * sin(th4) };


  // sub-assembly origin offset: p0 = R_apply(alp,bet, [L1,0,0])
  Vec3 p0 = R_apply(alp, bet, {L1, 0.0, 0.0});


  // E_global = p0 + R_apply(alp,bet, E_local)
  Vec3 Eg = R_apply(alp, bet, E_local);
  Eg.x += p0.x; Eg.y += p0.y; Eg.z += p0.z;


  return Eg;
}
void Leg::computeIK_FKSelect(){
  double x = pos[0], y = pos[1], z = pos[2];


  // ----- IK a,b,k (same as your computeIK) -----
  double l2 = x*x + y*y + z*z;
  double l  = sqrt(l2);
  if(l < 1e-6) l = 1e-6;


  double d2 = l2 - L1*L1;
  if(d2 < 0) d2 = 0;
  double d  = sqrt(d2);
  if(d < 1e-6) d = 1e-6;


  double cosK = (L1*L1 + (double)L2*L2 + (double)L3*L3 - l2) / (2.0*L2*L3);
  cosK = clampd(cosK, -1.0, 1.0);
  double theta_k = acos(cosK);


  double s1 = clampd(y/d, -1.0, 1.0);
  double cos2 = ((double)L2*L2 + d*d - (double)L3*L3) / (2.0*L2*d);
  cos2 = clampd(cos2, -1.0, 1.0);
  double theta_b = M_PI/2.0 - (asin(s1) + acos(cos2));


  double ca = clampd(L1 / l, -1.0, 1.0);
  double theta_a = atan2(x, fabs(z)) + acos(ca) - M_PI/2.0;


  // ----- IK theta_c roots -----
  double A = 2.0*r*(L4*cos(theta_k) + L2);
  double B = 6.0*r;
  double C = (double)r*r + pow((double)L2 + L4*cos(theta_k), 2)
           + 9.0 + pow(L4*sin(theta_k) - h, 2) - (double)L3*L3;


  double disc = (A*B)*(A*B) - (A*A - C*C)*(B*B - C*C);
  double sq = sqrt(fmax(disc, 0.0));


  double Y1 = -A*B + sq;
  double Y2 = -A*B - sq;
  double X  = A*A - C*C;


  double c1 = wrapPi(atan2(Y1, X));
  double c2 = wrapPi(atan2(Y2, X));


  // unwrap near last_c_local for continuity
  auto unwrapToNear = [&](double a, double ref){
    return ref + angDiff(a, ref);
  };


  double c1u = c1, c2u = c2;
  if(inited_c){
    c1u = unwrapToNear(c1, last_c_local);
    c2u = unwrapToNear(c2, last_c_local);
  }


  // ----- evaluate both by FK end-effector error -----
  Vec3 E1 = fkEndEffector(theta_a, theta_b, c1u, false);
  Vec3 E2 = fkEndEffector(theta_a, theta_b, c2u, false);


  auto norm3 = [](double dx,double dy,double dz){
    return sqrt(dx*dx + dy*dy + dz*dz);
  };


  double pos_err1 = norm3(E1.x-x, E1.y-y, E1.z-z);
  double pos_err2 = norm3(E2.x-x, E2.y-y, E2.z-z);


  double cont1 = inited_c ? fabs(c1u - last_c_local) : 0.0;
  double cont2 = inited_c ? fabs(c2u - last_c_local) : 0.0;


  // weights: match MATLAB
  const double w_pos  = 1.0;
  const double w_cont = 0.05;
  const double hys    = 0.5;


  double J1 = w_pos*pos_err1 + w_cont*cont1;
  double J2 = w_pos*pos_err2 + w_cont*cont2;


  int pick;
  if(!inited_pick){
    pick = (J1 <= J2) ? 1 : 2;
    inited_pick = true;
    inited_c = true;
  }else{
    if(last_pick == 1){
      pick = (J2 < J1 - hys) ? 2 : 1;
    }else{
      pick = (J1 < J2 - hys) ? 1 : 2;
    }
  }


  double chosen = (pick==1) ? c1u : c2u;


  // commit theta4 memory with chosen
  (void)fkEndEffector(theta_a, theta_b, chosen, true);


  last_c_local = chosen;
  last_pick = pick;


  angle1 = wrapPi(theta_a);
  angle2 = wrapPi(theta_b);
  angle3 = chosen;


  // debug
  debug_a1 = angle1; debug_a2 = angle2; debug_a3 = angle3;
}




// -----------------------------
//  Globals
// -----------------------------
IntervalTimer controlTimer;
volatile bool doUpdate = false;
double tt = 0.0;
Leg RF;
Leg LF;
Leg RB;
Leg LB;

static constexpr size_t USB_LINE_MAX = 256;
char usbLine[USB_LINE_MAX];
size_t usbLineLen = 0;
bool usbLineOverflow = false;

uint32_t heartbeatSeq = 0;
unsigned long lastHeartbeatMs = 0;
unsigned long lastCommandMs = 0;
unsigned long lastFailsafeStandMs = 0;

const double STAND_DEG[12] = {
   0.0, -69.636, -33.474,
  -0.0,  69.636,  33.474,
   0.0,  69.636,  33.474,
  -0.0, -69.636, -33.474
};




// -----------------------------
//  Motor packet (SYNC WRITE 12 motors)
//  - a1..a12 in RAD (internal)
// -----------------------------
void sendMotorPacketRad(double a1, double a2, double a3,
                        double a4, double a5, double a6,
                        double a7, double a8, double a9,
                        double a10,double a11,double a12)
{
  // safety clamp
  auto clampRad = [](double r){
    return clampd(r, deg2rad(-LIMIT_DEG), deg2rad(LIMIT_DEG));
  };


  const uint8_t header[] = {0xFF, 0xFF, 0xFE, 0x58, 0x83, 0x2A, 0x06};
  uint8_t packet[150];
  int idx = 0;


  memcpy(packet, header, sizeof(header));
  idx += sizeof(header);


  const uint8_t ids[12] = {1,2,3,4,5,6,7,8,9,10,11,12};


  double rad[12] = {
    clampRad(a1), clampRad(a2), clampRad(a3),
    clampRad(a4), clampRad(a5), clampRad(a6),
    clampRad(a7), clampRad(a8), clampRad(a9),
    clampRad(a10),clampRad(a11),clampRad(a12)
  };


  uint16_t goal[12];
  for(int i=0;i<12;i++){
    goal[i] = centerPlusRad(rad[i]);
  }


  for(int i=0;i<12;i++){
    packet[idx++] = ids[i];


    // position 0x2A
    packet[idx++] = (goal[i] >> 0) & 0xFF;
    packet[idx++] = (goal[i] >> 8) & 0xFF;


    packet[idx++] = 0x00;                // 資料長度低位
    packet[idx++] = 0x01;                // 資料長度高位
    packet[idx++] = 0xE8;    // 位置值低位
    packet[idx++] = 0x03; // 位置值高位
  }


  // checksum: sum from 0xFE
  uint8_t sum = 0;
  for (int i = 2; i < idx; i++) {
    sum += packet[i];
  }
  uint8_t checksum = ~sum;


  packet[idx++] = checksum;




  Serial4.write(packet, idx);
}


// Convenience: send in DEG (more human-friendly)
void sendMotorPacketDeg(double d1, double d2, double d3,
                        double d4, double d5, double d6,
                        double d7, double d8, double d9,
                        double d10,double d11,double d12)
{
  sendMotorPacketRad(deg2rad(d1), deg2rad(d2), deg2rad(d3),
                     deg2rad(d4), deg2rad(d5), deg2rad(d6),
                     deg2rad(d7), deg2rad(d8), deg2rad(d9),
                     deg2rad(d10),deg2rad(d11),deg2rad(d12));
}

void sendMotorPacketDegArray(const double deg[12])
{
  sendMotorPacketDeg(
    deg[0],  deg[1],  deg[2],
    deg[3],  deg[4],  deg[5],
    deg[6],  deg[7],  deg[8],
    deg[9],  deg[10], deg[11]
  );
}

void sendStandPose()
{
  sendMotorPacketDegArray(STAND_DEG);
}

void sendAck(uint32_t seq, bool ok)
{
  Serial.print("$ACK,");
  Serial.print(seq);
  Serial.print(",");
  Serial.println(ok ? 1 : 0);
}

void sendHeartbeat()
{
  Serial.print("$HB,");
  Serial.println(++heartbeatSeq);
}

uint32_t parseSeqBestEffort(const char* line)
{
  if(strncmp(line, "$ANGLES,", 8) != 0) return 0;
  char* end = nullptr;
  unsigned long seq = strtoul(line + 8, &end, 10);
  if(end == line + 8) return 0;
  return (uint32_t)seq;
}

bool parseAnglesLine(const char* line, uint32_t& seq, double deg[12])
{
  if(strncmp(line, "$ANGLES,", 8) != 0) return false;

  const char* p = line + 8;
  char* end = nullptr;

  unsigned long parsedSeq = strtoul(p, &end, 10);
  if(end == p || *end != ',') return false;
  seq = (uint32_t)parsedSeq;
  p = end + 1;

  for(int i = 0; i < 12; ++i){
    deg[i] = strtod(p, &end);
    if(end == p) return false;
    if(!isfinite(deg[i])) return false;
    p = end;

    if(i < 11){
      if(*p != ',') return false;
      ++p;
    }else{
      while(*p == ' ' || *p == '\t' || *p == '\r') ++p;
      if(*p != '\0') return false;
    }
  }

  return true;
}

void handleCommandLine(const char* line)
{
  if(strncmp(line, "$ANGLES,", 8) != 0){
    return;
  }

  uint32_t seq = 0;
  double deg[12];
  if(parseAnglesLine(line, seq, deg)){
    sendMotorPacketDegArray(deg);
    lastCommandMs = millis();
    sendAck(seq, true);
  }else{
    sendAck(parseSeqBestEffort(line), false);
  }
}

void handleUsbSerial()
{
  while(Serial.available() > 0){
    char c = (char)Serial.read();

    if(c == '\r'){
      continue;
    }

    if(c == '\n'){
      if(!usbLineOverflow){
        usbLine[usbLineLen] = '\0';
        handleCommandLine(usbLine);
      }
      usbLineLen = 0;
      usbLineOverflow = false;
      continue;
    }

    if(usbLineOverflow){
      continue;
    }

    if(usbLineLen < USB_LINE_MAX - 1){
      usbLine[usbLineLen++] = c;
    }else{
      usbLineLen = 0;
      usbLineOverflow = true;
    }
  }
}


// -----------------------------
//  Trajectory (safe small ellipse)
// -----------------------------
void lift_trajectory(Leg& leg, double t){
  const double x0  = 26.086;
  const double y0 = 0.0;
  const double z0 = -150.0;
  //const double Ay = 20.0;
  //const double Az = 10.0;


  double x = x0;
  double y = y0;


  double s = 0.5 * (1.0 - cos(2.0 * omega * t)); // 0..1..0
  double z = z0 + lift * s;


  leg.setTargetPosition(x, y, z);


  return;
}
void sinusoidal_trajectory(Leg& leg, double p, double duty){
  p = wrap01(p);


  const double x0 = 26.086;
  const double y0 = 0.0;
  const double z0 = -150.0;


  if(p < duty){
    // Stance phase: push backward
    double u = p / duty;
    double y = y0 + disp * (0.5 - u);
    leg.setTargetPosition(x0, y, z0);  // ← 加這行
  }else{
    // Swing phase: lift and move forward
    double u = (p - duty) / (1.0 - duty);
    double y = y0 + disp * (u - 0.5);
    double z = z0 + lift * sin(M_PI * u);
    leg.setTargetPosition(x0, y, z);
  }
}
void standing_pose(Leg& leg){
  const double x  = 26.086;
  const double y = 0.0;
  const double z = -150.0;
  leg.setTargetPosition(x, y, z);
}
void squat_pose(Leg& leg){
  const double x  = 26.086;
  const double y = 0.0;
  const double z = -80.0;
  leg.setTargetPosition(x, y, z);
}
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
void loop(){
  if(ENABLE_ROS_BRIDGE){
    handleUsbSerial();

    unsigned long now = millis();
    if(now - lastHeartbeatMs >= HEARTBEAT_MS){
      lastHeartbeatMs = now;
      sendHeartbeat();
    }

    if(now - lastCommandMs >= COMMAND_TIMEOUT_MS &&
       now - lastFailsafeStandMs >= FAILSAFE_STAND_MS){
      lastFailsafeStandMs = now;
      sendStandPose();
    }

    return;
  }

  //control gait here
  static bool enable_trot = true;
  static bool enable_walk = false;
  static bool enable_lean = false;
  double dt = CTRL_US / 1000000.0;
  if(ENABLE_TIMER && doUpdate){
    doUpdate = false;
   
    tt += dt; //20000/1000000.0 = 0.02
    //if(tt > 2.0*M_PI) tt -= 2.0*M_PI;
    phase = wrap01(phase + phaseRate * dt) ;  // dt = 20ms


    if(ENABLE_TRAJ){
      if(enable_lean){
        lean(RB, RF, LB, LF);
      }
      else if(enable_walk){
        walk(RB, RF, LB, LF, phase);
      }
      else if(enable_trot){
        trot(RB, RF, LB, LF, phase);
      }
      else {
        //STAND
        standing_pose(RB);
        standing_pose(RF);


        standing_pose(LB);
        standing_pose(LF);
       
        LB.computeIK_FKSelect();
        RF.computeIK_FKSelect();
        RB.computeIK_FKSelect();
        LF.computeIK_FKSelect();
      }






    sendMotorPacketDeg(
      rad2deg(LB.angle1), (-1)*rad2deg(LB.angle2), rad2deg(LB.angle3),
      (-1)*rad2deg(RB.angle1), rad2deg(RB.angle2) ,  (-1)*rad2deg(RB.angle3),
      rad2deg(RF.angle1), rad2deg(RF.angle2), (-1)*rad2deg(RF.angle3),
      (-1)*rad2deg(LF.angle1), (-1)*rad2deg(LF.angle2), rad2deg(LF.angle3)
    );
    }
  }


  // debug print every 200ms
  /*unsigned long now = millis();
  if(now - lastPrintTime >= 200){
    lastPrintTime = now;


    Serial.print("x: "); Serial.print((double)debug_x, 3);
    Serial.print(", y: "); Serial.print((double)debug_y, 3);
    Serial.print(", z: "); Serial.println((double)debug_z, 3);


    Serial.print("a1(rad): "); Serial.print((double)debug_a1, 6);
    Serial.print(", a2(rad): "); Serial.print((double)debug_a2, 6);
    Serial.print(", a3(rad): "); Serial.println((double)debug_a3, 6);
  }*/
}

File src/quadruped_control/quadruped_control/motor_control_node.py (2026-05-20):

#!/usr/bin/env python3
"""
motor_control_node.py
---------------------
Subscribes:
  /joint_angles  [std_msgs/Float32MultiArray]   12 floats in degrees

Writes to Teensy via USB Serial:
  Protocol: $ANGLES,<seq>,d1,d2,...,d12\n   (ASCII, ~170 bytes/line)

Reads from Teensy:
  $ACK,<seq>,1\n           — Jetson→Teensy ACK
  $HB,<teensy_seq>\n       — Teensy→Jetson heartbeat (10 Hz)

Publishes:
  /comm_stats  [std_msgs/String]  JSON drop stats every 1 s  (→ rosbag)
  /teensy_ack  [std_msgs/String]  raw ACK lines              (→ rosbag)
  /teensy_hb   [std_msgs/String]  raw HB  lines              (→ rosbag)
"""

import json, threading, time
import rclpy
from rclpy.node import Node
from std_msgs.msg import Float32MultiArray, String
import serial as pyserial
from serial import SerialException


class MotorControlNode(Node):
    def __init__(self):
        super().__init__('motor_control_node')

        self.declare_parameter('serial_port', '/dev/ttyACM0')
        self.declare_parameter('baud_rate',   115200)
        self._port = self.get_parameter('serial_port').value
        self._baud = int(self.get_parameter('baud_rate').value)

        # ── serial ──
        self._ser = None
        self._serial_lock = threading.Lock()
        self._last_serial_error_log = 0.0
        self._connect_serial()

        # ── drop tracking ──
        self._tx_seq  = 0
        self._tx_sent = self._tx_acked = self._tx_nacked = 0

        self._hb_last     = None
        self._hb_received = self._hb_dropped = 0

        # ── ROS ──
        self.create_subscription(Float32MultiArray, '/joint_angles',
                                 self._angles_cb, 10)
        self._stats_pub = self.create_publisher(String, '/comm_stats', 10)
        self._ack_pub   = self.create_publisher(String, '/teensy_ack', 10)
        self._hb_pub    = self.create_publisher(String, '/teensy_hb',  10)

        threading.Thread(target=self._reader, daemon=True).start()
        self.create_timer(1.0, self._reconnect_timer)
        self.create_timer(1.0, self._publish_stats)
        self.get_logger().info(
            f"MotorControlNode → {self._port} @ {self._baud}")

    # ── helpers ───────────────────────────────────────────────────────────────
    def _connect_serial(self):
        with self._serial_lock:
            if self._ser is not None and self._ser.is_open:
                return True

            try:
                ser = pyserial.Serial(
                    self._port, self._baud, timeout=0.005, write_timeout=0.02)
                self._ser = ser
            except Exception as e:
                now = time.monotonic()
                if now - self._last_serial_error_log >= 1.0:
                    self._last_serial_error_log = now
                    self.get_logger().warn(
                        f"Serial reconnect failed ({self._port}): {e}")
                return False

        self._lower_latency(self._port)
        self.get_logger().info(f"Serial connected: {self._port} @ {self._baud}")
        return True

    def _disconnect_serial(self, context: str, error: Exception):
        with self._serial_lock:
            ser = self._ser
            self._ser = None

        if ser is not None:
            try:
                ser.close()
            except Exception:
                pass

        now = time.monotonic()
        if now - self._last_serial_error_log >= 1.0:
            self._last_serial_error_log = now
            self.get_logger().error(
                f"Serial {context}: {error}; disconnected, will retry")

    def _reconnect_timer(self):
        if self._ser is None:
            self._connect_serial()

    def _lower_latency(self, port: str):
        try:
            dev = port.split('/')[-1]
            with open(f"/sys/bus/usb-serial/devices/{dev}/latency_timer", 'w') as f:
                f.write('1')
            self.get_logger().info(f"USB latency timer → 1 ms ({dev})")
        except Exception as e:
            self.get_logger().warn(f"latency_timer: {e}")

    # ── TX ────────────────────────────────────────────────────────────────────
    def _angles_cb(self, msg: Float32MultiArray):
        if len(msg.data) != 12:
            self.get_logger().warn(f"Expected 12 angles, got {len(msg.data)}")
            return

        self._tx_seq += 1
        seq = self._tx_seq
        vals = ",".join(f"{v:.3f}" for v in msg.data)
        line = f"$ANGLES,{seq},{vals}\n"
        try:
            with self._serial_lock:
                if self._ser is None:
                    return
                self._ser.write(line.encode())
            self._tx_sent += 1
        except SerialException as e:
            self._disconnect_serial("write", e)
        except Exception as e:
            self._disconnect_serial("write", e)

    # ── RX ────────────────────────────────────────────────────────────────────
    def _reader(self):
        buf = b""
        while True:
            try:
                ser = self._ser
                if ser is None:
                    time.sleep(0.05)
                    continue

                chunk = ser.read(ser.in_waiting or 1)
                if chunk:
                    buf += chunk
                    while b'\n' in buf:
                        raw, buf = buf.split(b'\n', 1)
                        self._handle(raw.decode('ascii', errors='ignore').strip())
            except SerialException as e:
                self._disconnect_serial("read", e)
                buf = b""
                time.sleep(0.05)
            except Exception as e:
                self._disconnect_serial("read", e)
                buf = b""
                time.sleep(0.01)

    def _handle(self, line: str):
        if line.startswith('$ACK'):
            pub_msg = String(); pub_msg.data = line
            self._ack_pub.publish(pub_msg)
            try:
                _, seq_s, ok_s = line.split(',')
                if int(ok_s):
                    self._tx_acked  += 1
                else:
                    self._tx_nacked += 1
            except Exception:
                pass

        elif line.startswith('$HB'):
            pub_msg = String(); pub_msg.data = line
            self._hb_pub.publish(pub_msg)
            try:
                teensy_seq = int(line.split(',')[1])
                self._hb_received += 1
                if self._hb_last is not None:
                    gap = teensy_seq - self._hb_last - 1
                    if gap > 0:
                        self._hb_dropped += gap
                self._hb_last = teensy_seq
            except Exception:
                pass

    # ── stats ─────────────────────────────────────────────────────────────────
    def _publish_stats(self):
        tx_drop = (100.0 * (self._tx_sent - self._tx_acked) / self._tx_sent
                   if self._tx_sent else 0.0)
        rx_total = self._hb_received + self._hb_dropped
        rx_drop  = (100.0 * self._hb_dropped / rx_total if rx_total else 0.0)
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

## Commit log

2026-05-16 Initial doggy ROS workspace
    [.scad, calf.scad, feetech_sts2032_20g.stl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]
2026-05-16 urdf completed, workflow added
2026-05-16 Add RL deployment nodes
    [hipjoint_v4__2.stl, robot.urdf]
2026-05-20 urdf editted
    [robot.urdf]
